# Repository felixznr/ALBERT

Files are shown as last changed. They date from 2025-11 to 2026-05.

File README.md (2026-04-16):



# ALBERT

Albert I was a rhesus macaque monkey and the first mammal launched on a rocket (V-2 Rocket "Blossom No. 3") on June 18, 1948. The launch was staged at Albert I, a nine-pound monkey, was anesthetized and placed inside the rocket's crew capsule in the nose of the V-2 rocket. The flight did not reach outer space. The last couple hours before his death, Albert was lit asf on morphine

---

## Project Overview

ALBERT is a self-regulating guided rocket project developed as a Maturaprojekt (Austrian graduation project). The goal is to build a fully functional, autonomous rocket system capable of correcting its own flight path and safely recovering via parachute deployment.

**Key Objectives:**
- Develop autonomous flight path correction through advanced control systems
- Implement fin-based steering for precise guidance
- Create a reliable parachute recovery system
- Design a concept of a custom solid fuel motor
- Integrate comprehensive telemetry and safety systems

## Team Structure

- **Timofey Luzin**: Recovery system, steering system, and structural components
- **Felix Zauner**: Flight computer development, control systems, simulation, and telemetry

## Repository Organization

```
├── 1_Documentation/        # Project documentation and requirements
├── 2_CAD_Structure/        # 3D models and structural designs  
├── 3_Flight_Computer/      # Flight computer hardware
├── 4_Simulation/           # Flight simulation and testing tools
└── 5_Codebase/             # Main source code and algorithms
```

For detailed technical specifications, see `1_Documentation/Diplomarbeit_ALBERT/chapter/main.pdf`.

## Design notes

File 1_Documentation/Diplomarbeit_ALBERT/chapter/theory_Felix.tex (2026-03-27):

\chapter{Platinendesign}
\label{ch:platinendesign}
\fancyfoot[C]{\large Felix Zauner}
\fancypagestyle{plain}{\fancyfoot[C]{\large Felix Zauner}}
Eine Platine ist eine gedruckte Schaltung (Printed Circuit Board, PCB in Englisch), die dazu dient, elektronische Bauteile miteinander zu verbinden. In diesem Kapitel werden die Grundlagen des Platinendesigns erörtert, einschließlich der Auswahl von Bauteilen, Layout-Strategien und Fertigungstechniken.
\\
Im Rahmen des Projektes wurde die Software KiCad eingesetzt, um den Schaltplan als auch das Layout der Platine zu erstellen. KiCad ist eine Open-Source-Software, die eine Vielzahl von Werkzeugen für das Design von Leiterplatten bereitstellt.
\\
Es ist von essentieller Bedeutung, sich vorab mit den Anforderungen an die Platine vertraut zu machen. Bei der Auswahl von Komponenten sind eine Vielzahl von Faktoren zu berücksichtigen. Dazu zählen elektrische Anforderungen, wie beispielsweise die Spannungs- und Stromstärken, mechanische Anforderungen, wie die Größe und Form der Platine, sowie Umweltanforderungen, wie die Betriebstemperatur, die Feuchtigkeitsbeständigkeit, aber auch Vibrationen und externe Störungen, Stichwort EMV, müssen, besonders bei der Bauteilauswahl, berücksichtigt werden.
\\
\\
Es ist in allen folgenden Punkten essentiell, sich zuvor mit den Produktionskapazitäten und -anforderungen des gewählten Platinenherstellers vertraut zu machen, um sicherzustellen, dass das Design den Fertigungsspezifikationen entspricht und somit eine reibungslose Produktion gewährleistet ist.
Darüber hinaus ist es ratsam, die Grenzen der Fertigungskapazitäten zu meiden, um Zusatzkosten zu vermeiden und potenzielle Fehlerquellen zu minimieren.

\section{Build-up \& Stack-up}
\label{sec:buildup_stackup}
\subsection{Build-up}
\label{subsec:buildup}

\begin{wrapfigure}{r}{0.5\textwidth}

    % {r} = rechtsbündig platzieren
    % Alternativen: {l} = links, {i} = innen (bei zweiseitigem Druck), {o} = außen
    % 0.4\textwidth = Gesamtbreite inkl. Abstand zum Text
    \centering
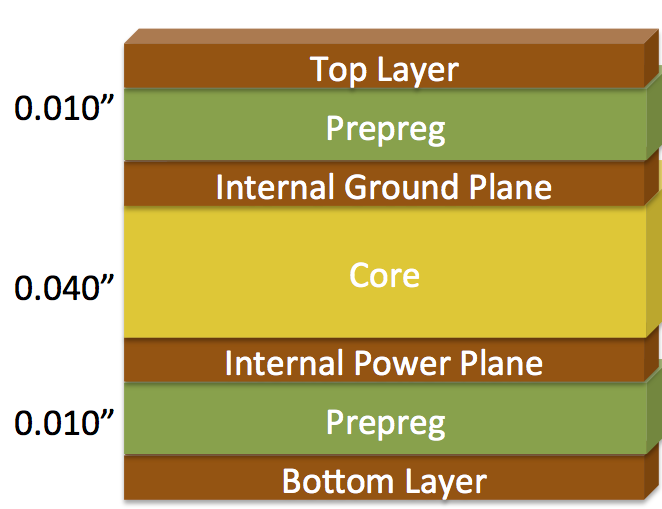
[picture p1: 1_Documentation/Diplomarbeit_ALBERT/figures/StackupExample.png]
    
        \caption{Beispielhafter Stackup einer vierlagigen Leiterplatte \parencite{bitweenie2013}}
        \label{fig:stackup_example}
    % Bildbreite etwas kleiner als wrapfigure-Breite (Abstand zum Text)

  % Abstand nach dem Bild reduzieren
\end{wrapfigure}
Der Leiterplattenaufbau (Build-up) einer Leiterplatte beschreibt den physikalischen Aufbau und die Anordnung der verschiedenen Schichten, aus denen die Platine besteht. Ein charakteristisches Build-up besteht aus einer Mehrzahl von Kupferschichten, die durch Isolationsmaterialien voneinander getrennt sind. Die Anzahl der Schichten sowie die Auswahl des dielektrischen Isolationsmaterials sind abhängig von der Komplexität der Schaltung und den Anforderungen an Signalqualität und Leistung. 
\\
In der Planungsphase sind primär die Anzahl der erforderlichen Lagen, die Auswahl der Isolationsmaterialien für den Kern sowie Prepreg und die Dicke der inneren und äußeren Kupferschichten festzulegen. \parencite{PhilsLab56}
\\
Die Abbildung \ref{fig:stackup_example} zeigt ein beispielhaftes Build-up und Stack-up einer vierlagigen Leiterplatte.
\\
\subsection{Stack-up}
\label{subsec:stackup}
Das Stack-up einer Leiterplatte beschreibt die Anordnung der verschiedenen Schichten in Bezug auf die elektrische Verwendung und Funktionalität. Das Stack-up umfasst die Definition von:
\begin{itemize}
        \item Ground-Layers $\rightarrow$ Referenzpotential für die Schaltung, Rückstrompfade
        \item Power-Layers  $\rightarrow$ Versorgungsspannungen für die Schaltung
        \item Signal-Layers $\rightarrow$ Leiterbahnen für die Signalübertragung
\end{itemize}
Des Weiteren besteht die Möglichkeit, Power- und Ground-Planes\footnote{Plane: Eine durchgehende Kupferfläche auf einer Leiterplattenlage, die als Referenzpotential oder Versorgungsspannung dient.} sowie Signal- und Ground-Planes auf einem Layer zu kombinieren. Auf diese Weise kann etwa auf zweilagigen Platinen Platz eingespart werden.
\\
Die Anordnung dieser Schichten im Stack-up ist entscheidend für gute EMV/EMI Eigenschaften, Signalintegrität und Leistungsverteilung. Ein gut durchdachtes Stack-up minimiert Störungen, verbessert die Signalqualität und gewährleistet eine zuverlässige Funktion der Schaltung.
\\\\
Die im folgenden Abschnitten beschriebenen Konzepte stellen die wichtigsten Prinzipien dar, die bei der Gestaltung eines effektiven Stack-ups zu berücksichtigen sind.
\subsubsection{Rückstrompfade}
\label{subsubsec:rueckstrompfade}
Ein kritischer Aspekt im Platinendesign ist die Gestaltung der Rückstrompfade für Signale. \\Rückstrompfade sind die Wege, die der Strom zurück zum Ursprungspunkt nimmt, nachdem er durch die Schaltung geflossen ist. 
\\
Für Gleichspannung nimmt der Rückstrom den Weg des geringsten ohmschen Widerstands über die nächste Massefläche. Bei Wechselspannung ($>kHz$) hingegen folgt der Rückstrompfad dem Signalpfad, da die kapazitive und induktive Kopplung zwischen den Leitungen dominant wird. \parencite{ZachariahPeterson_Rückstromführung}

\begin{figure}[H]
  \centering
  % Erste Unterabbildung (Subfigure)
  \begin{subfigure}[b]{0.49\textwidth}
    % [b] = bottom-aligned (unten ausgerichtet)
    % Alternativen: [t] = top, [c] = center
    % 0.45\textwidth = 45% der Textbreite
    \centering
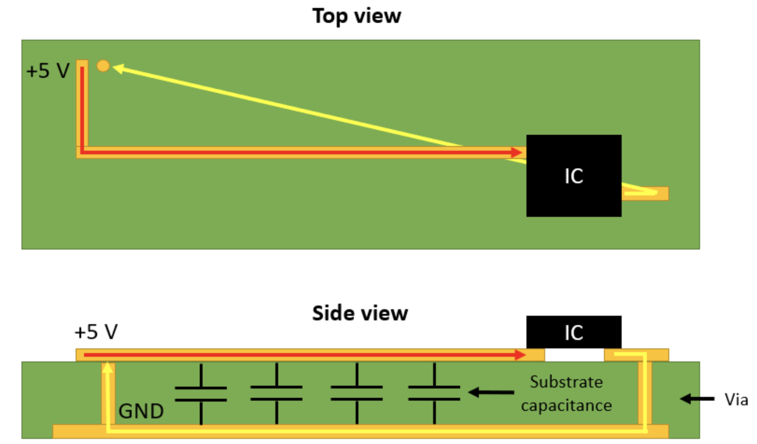
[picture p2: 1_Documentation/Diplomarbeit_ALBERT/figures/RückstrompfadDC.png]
    
    % \textwidth bezieht sich hier auf die Subfigure-Breite (45%)
    \caption{Rückstrompfad für Gleichstrom}
    % Separate Bildunterschrift für diese Subfigure
    \label{fig:sub-mercedes}
    % Eigenes Label für Referenzierung
  \end{subfigure}
  \hfill
  % \hfill = maximaler horizontaler Abstand (verteilt Bilder gleichmäßig)
  % Alternative: \hspace{1cm} für festen Abstand
  \begin{subfigure}[b]{0.49\textwidth}
    \centering
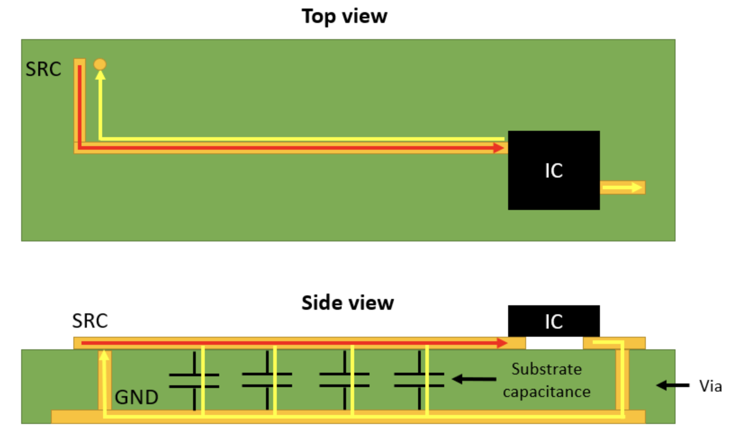
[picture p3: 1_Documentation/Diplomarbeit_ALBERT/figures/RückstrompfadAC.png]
    
    \caption{Rückstrompfad für Wechselstrom}
    \label{fig:sub-porsche}
  \end{subfigure}
  \caption{Rückstrompfade im Vergleich \parencite{ZachariahPeterson_Rückstromführung}}
  % Gemeinsame Hauptbildunterschrift für beide Subfigures
  \label{fig:zwei-neben}
  % Hauptlabel für die gesamte Figure
\end{figure}
\newpage
\subsubsection{Energiefluss}
\label{subsubsec:energiefluss}
Für eine optimale Signalübertragung und minimale Störungen ist es entscheidend, den Energiefluss zwischen den Leiterbahnen und den zugehörigen Ground- und Power-Planes zu verstehen. 
\begin{wrapfigure}{r}{0.5\textwidth}

  % {r} = rechtsbündig platzieren
  % Alternativen: {l} = links, {i} = innen (bei zweiseitigem Druck), {o} = außen
  % 0.4\textwidth = Gesamtbreite inkl. Abstand zum Text
  \centering
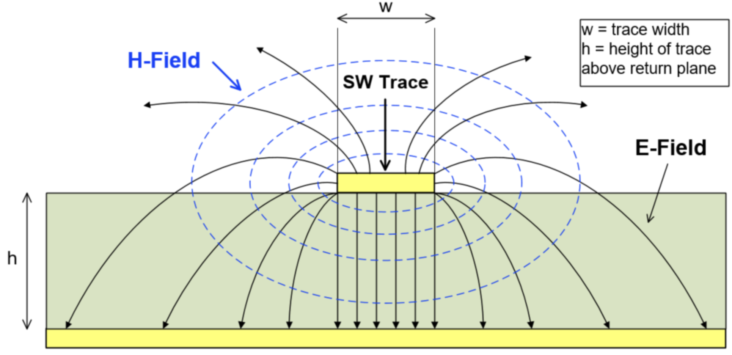
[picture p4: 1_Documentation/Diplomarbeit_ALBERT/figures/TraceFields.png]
  
    \caption{Elektrisches und magnetisches Feld eines Leiterbahnschnitts \parencite{ToddToporski_EMC}}
    \label{fig:trace_fields}
  % Bildbreite etwas kleiner als wrapfigure-Breite (Abstand zum Text)

    % Abstand nach dem Bild reduzieren
\end{wrapfigure}
Jede Leiterbahn erzeugt ein elektrisches Feld (E-Feld) und ein magnetisches Feld (H-Feld) um sich herum, wenn Strom durch sie fließt. Die Energieübertragung erfolgt durch diese Felder. Das elektrische Feld ist zwischen der Leiterbahn und dem nächstgelegenen Ground-Plane konzentriert, während das magnetische Feld konzentrisch um die Leiterbahn verläuft.
Dabei stellen die Kupferbahnen den Waveguide für die Felder dar. 
\\
Die Abbildung \ref{fig:trace_fields} veranschaulicht die Verteilung der elektrischen und magnetischen Felder um eine Leiterbahn.
\\\\
Um nun die Signalintegrität zu gewährleisten und Crosstalk \footnote{Crosstalk bezeichnet bei Leiterplatten das unerwünschte Übersprechen von Signalen zwischen benachbarten Leiterbahnen, verursacht durch kapazitive und induktive Kopplung} sowie EMI zu minimieren, ist es wichtig, dass sich die Felder der Leiterbahnen nicht ausbreiten und mit deren von benachbarten Leiterbahnen verursachten Feldern koppeln. 
\\
Dies kann durch zwei wesentliche Maßnahmen erreicht werden:
\begin{itemize}
    \item Minimierung des Abstands $h$ zwischen der Leiterbahn und dem zugehörigen Ground-Plane
    \item Maximierung des Abstands zu benachbarten Leiterbahnen
\end{itemize}
\vspace{0.5cm}
Aus diesen beiden Punkten können folgende Designregeln für das Layout der Leiterplatte abgeleitet werden:
\begin{itemize}
    \item Der Abstand $h$ zwischen der Leiterbahn und der zugehörigen Ground-Plane sollte so klein wie möglich gehalten werden, daher wäre es ideal, wenn jede Signal-Leiterbahn direkt über einer Ground-Plane verlaufen würde.
    \item Jede Signal-Leiterbahn sollte einen ununterbrochenen Rückstrompfad haben.
\end{itemize}
\parencite{PhilsLab56}
\newpage

\section{Bypass- \& Decoupling-Kondensatoren}
\label{sec:bypass_decoupling}
Bypass- und Decoupling-Kondensatoren sind wesentliche Komponenten in der Entwicklung von Leiterplatten, die dazu dienen, Störungen zu minimieren und eine stabile Versorgungsspannung für ICs bereitzustellen. Oft werden die Begriffe Bypass- und Decoupling-Kondensatoren synonym verwendet, obwohl sie strenggenommen unterschiedliche Funktionen erfüllen.
\\\\
\textbf{Bypass-Kondensatoren} werden verwendet, da Kondensatoren bei hohen Frequenzen einen niedrigen Impedanzwert aufweisen. Sie leiten hochfrequente Störsignale von der Versorgungsspannung gegen Masse ab und dienen als Filter, um zu verhindern, dass Störungen in die Schaltung eindringen und die Funktion der Bauteile beeinträchtigen.
\\\\
\textbf{Decoupling-Kondensatoren} hingegen werden direkt an den Versorgungspins von ICs platziert, um schnelle Stromänderungen lokal auszugleichen, die durch das Schalten der internen Transistoren verursacht werden. Sie stellen sicher, dass die Versorgungsspannung stabil bleibt und verhindert Spannungsschwankungen.
\parencite{JLCDecouplingBypass}
\\\\
Bei der Platzierung von Bypass- und Decoupling-Kondensatoren auf der Leiterplatte sind folgende Richtlinien zu beachten:
\begin{itemize}
    \item \textbf{Nähe zum IC}: Decoupling-Kondensatoren sollten so nah wie möglich an den Versorgungspins des ICs platziert werden und mit möglichst breiten Leiterbahnen verbunden werden, um die Induktivität der Leiterbahnen zu minimieren. Die Vias zu Masse und Power sollten ebenfalls so nah wie möglich am Kondensator platziert werden.
    \item \textbf{Verschiedene Werte}: In vielen Fällen erweist es sich als sinnvoll, mehrere \\Decoupling-Kondensatoren mit unterschiedlichen Kapazitätswerten (typischerweise $100nF$ und $10 \mu F$, Keramik) zu verwenden. Aufgrund der Tatsache, dass kleinere Kondensatoren dazu in der Lage sind, Energie schneller bereitzustellen, empfiehlt es sich, diese näher am IC zu platzieren. 
    \item \textbf{Bypass-Kondensatoren}: Diese sollten strategisch in der Nähe von kritischen Versorgungspunkten auf der Platine platziert werden, um Störungen effektiv abzuleiten. So etwa an der Analogversorgung von Mikrocontrollern.
\end{itemize}
Auch hier gilt wieder, die Empfehlungen des Herstellers der jeweiligen Bauteile zu beachten um eine optimale Funktion zu gewährleisten.
\begin{figure}[H]
\centering
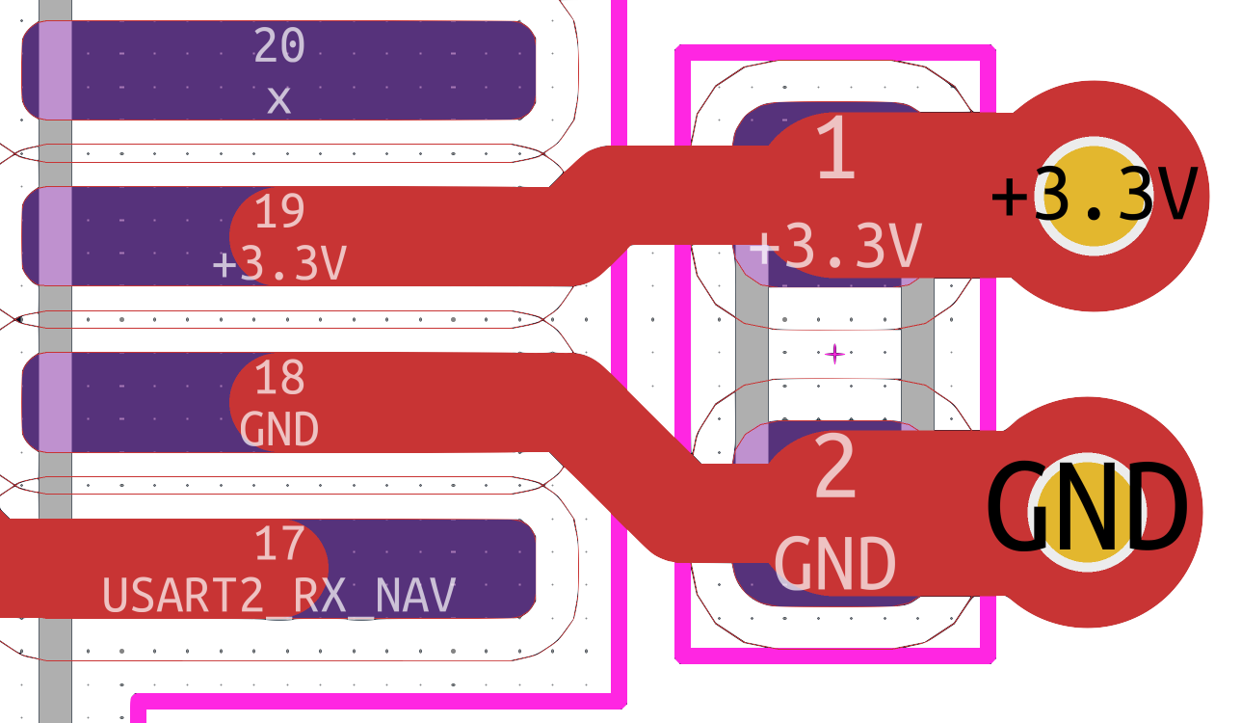
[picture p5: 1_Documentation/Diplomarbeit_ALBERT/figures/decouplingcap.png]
    
    \caption{Platzierung von Decoupling-Kondensatoren}
    \label{fig:decoupling_cap}
\end{figure}
\newpage
\section{Abwärtswandler}
\label{sec:abwaertswandler}
Der Abwärtswandler (Buck Converter) ist ein DC-DC-Wandler, der eine höhere Eingangsspannung in eine niedrigere Ausgangsspannung umwandelt. Durch einen getakteten Schaltvorgang wird die Energieübertragung gesteuert, was zu einer verbesserten Effizienz im Vergleich zu linearen Spannungsreglern führt.
\\
Für den kontinuierlichen Betrieb\footnote{kontinuierlicher Betrieb - der Strom $I_L$ wird während des gesamten Zykluses nie 0} gilt folgender Zusammenhang zwischen Ein- und Ausgangsspannung:
\begin{equation}
    U_{A} = U_{E} \cdot \frac{t_{1}}{T}
\end{equation}
\begin{figure}[H]
    \centering
    \begin{tikzpicture}
	% Paths, nodes and wires:
	\draw (4.875, 2) to[empty diode, l={$D$}] (4.875, 5);
	\draw (4.375, 5) to[european inductor, l={$L$}] (7.375, 5);
	\draw (6.875, 5) to[capacitor, l={$C_{A}$}] (6.875, 2);
	\draw (7.875, 5) -- (9.875, 5);
	\node[circ] at (0.335, 5){};
	\node[circ] at (0.335, 2){};
	\node[circ] at (9.875, 5){};
	\node[circ] at (9.875, 2){};
	\node[ground] at (4.875, 2){};
	\draw (7.875, 2) -- (9.875, 2);
	\draw[-stealth] (0.335, 4.75) -- (0.335, 2.25);
	\draw[line width=0.9pt, -stealth] (9.875, 4.75) -- (9.875, 2.25);
	\node[shape=rectangle, minimum width=0.965cm, minimum height=0.715cm](N1) at (-0.125, 3.625){} node[anchor=center] at (N1.text){$U_{E}$};
	\node[shape=rectangle, minimum width=0.965cm, minimum height=0.715cm](N2) at (10.375, 3.375){} node[anchor=center] at (N2.text){$U_{A}$};
	\draw[-stealth] (4.5, 5) -- (5.2, 5);
	\node[shape=rectangle, minimum width=0.965cm, minimum height=0.715cm](N3) at (4.9, 5.375){} node[anchor=center] at (N3.text){$I_{L}$};
	\draw[-stealth] (4.875, 4.25) -- (4.875, 4.5);
	\node[shape=rectangle, rotate=90, minimum width=0.965cm, minimum height=0.715cm](N4) at (4.625, 4.25){} node[anchor=center] at (N4.text){$I_{D}$};
	\draw[-stealth] (1.375, 5) -- (1.625, 5);
	\node[shape=rectangle, minimum width=0.965cm, minimum height=0.715cm](N5) at (1.335, 5.375){} node[anchor=center] at (N5.text){$I_{E}$};
	\draw[-stealth] (9.375, 5) -- (9.625, 5);
	\node[shape=rectangle, minimum width=0.965cm, minimum height=0.715cm](N6) at (9.375, 5.375){} node[anchor=center] at (N6.text){$I_{A}$};
	\node[nigfete, rotate=90](N7) at (2.605, 5){} node[anchor=south] at (N7.text){$Q$};
	\draw (3.375, 5) -- (4.375, 5);
	\draw (0.335, 5) -- (1.835, 5);
	\node[shape=rectangle, draw, line width=1pt, minimum width=1.715cm, minimum height=0.715cm] at (3.125, 3.375){};
	\node[shape=rectangle, minimum width=1.465cm, minimum height=0.715cm] at (3.125, 3.375){} node[anchor=north, align=center, text width=1.077cm, inner sep=6pt] at (2.83, 3.75){Controller};
	\draw (2.874, 4.02) -| (2.875, 3.75);
	\draw (8.375, 5) to[european resistor, l={$R_{FB1}$}] (8.375, 3.5);
	\draw (8.375, 3.5) to[european resistor, l={$R_{FB2}$}] (8.375, 2);
	\draw (6.875, 5) -- (7.875, 5);
	\draw (7.875, 2) -- (6.875, 2);
	\draw (6.835, 2) |- (4.335, 2) -- (0.335, 2);
	\draw[dash pattern={on 1.6pt off 1.6pt}] (2.875, 3) |- (3, 1) -| (9.625, 3.5) -- (8.375, 3.5);
	\draw (1.125, 5) to[capacitor, l={$C_{E}$}] (1.125, 2);
\end{tikzpicture}
    \caption{Vereinfachter Schaltplan eines Abwärtswandlers}
    \label{fig:buck_converter}
\end{figure}
\vspace{-2.5cm}
\subsection{Funktionsweise}
\label{subsec:buck_funktionsweise}
Der MOSFET $Q$ wird periodisch durch einen Regler (Controller) ein- und ausgeschaltet, wodurch während der Einschaltphase $t_{1}$ der Ausgangsstrom $I_{A}$ durch die Induktivität $L$ und die angeschlossene, aber hier nicht eingezeichnete Last fließt. Die Diode $D$ ist in dieser Phase gesperrt. Während der Ausschaltphase  hingegen sperrt der MOSFET $Q$ und die Induktivität $L$ entlädt sich über die Diode $D$ und die Last um den Stromfluss aufrechtzuerhalten. 
\\
Der Kondensator $C_A$ lädt sich in dieser Phase so lang auf bis beide das gleiche Potenzial erreicht haben, danach stützt er die Ausgangsspannung $U_{A}$. Der Eingangskondensator $C_E$ stellt die hochfrequenten, gepulsten Eingangsstromanteile bereit und wirkt dabei als lokaler Energiespeicher, wodurch Eingangsspannungsripple, Spannungsspitzen und EMV-Störungen reduziert und die Spannungsquelle entlastet werden. 
\\
Durch die kontinuierliche Ein- und Ausschaltphase wird eine mittlere Ausgangsspannung $\bar{U}_{A}$ erzeugt, die niedriger ist als die Eingangsspannung $U_{E}$ und über die Schaltfrequenz gesteuert werden kann.
\\
Über den Feedback-Widerstandsteiler $R_{FB1}$ und $R_{FB2}$ wird die Ausgangsspannung $U_{A}$ dem Controller zurückgeführt, der das Tastverhältnis $\frac{t_1}{T}$ (duty cycle) des MOSFETs $Q$ anpasst, um die gewünschte Ausgangsspannung zu halten.
\parencite{schmidt-walter_Abwärtswandler}\parencite{PhilsLab60}

\begin{figure}[H]
  \centering
  \begin{tikzpicture}[scale=1]

    % Gitternetz
      \draw[gray!20] (0,0) grid (9,5);
      \draw[gray!40] (0,0) grid[step=2] (9,5);

      % Bereich 1: MOSFET AN (0 bis t1)
      \draw[gray!20, fill=green!10] (0,0) -- (3,0) -- (3,5) -- (0,5) -- cycle;
      \node[green, anchor=south] at (1.5, 5) { Q AN};
      
      % Bereich 2: MOSFET AUS (t1 bis T)
      \draw[gray!20, fill=red!10] (3,0) -- (6,0) -- (6,5) -- (3,5) -- cycle;
      \node[red, anchor=south] at (4.5, 5) { Q AUS};

      % Bereich 1: MOSFET AN (0 bis t1)
      \draw[gray!20, fill=green!10] (6,0) -- (9,0) -- (9,5) -- (6,5) -- cycle;
      \node[green, anchor=south] at (7.5, 5) { Q AN};
      
      % --- U_Q (Schaltspannung) ---
      \draw[line width=1pt, blue!50] (0,5) -- (3,5) -- (3,0) -- (6,0) -- (6,5) -- (9,5);
      \node[blue!50, left] at (0,4.5) {$U_Q$};
      
      % --- U_A (Ausgangsspannung) ---

      \draw[line width=1.5pt, orange] (0,2.5) -- (1.5,2);

      \draw[line width=1.5pt, orange] (1.5,2) -- (4.5,3);
      \draw[line width=1.5pt, orange] (4.5,3) -- (6,2.5);
      \draw[line width=1.5pt, orange] (6,2.5) -- (7.5,2);
      \draw[line width=1.5pt, orange] (7.5,2) -- (9,2.5);
       
      \node[orange, left] at (0,2.8) {$U_A$};
      
      % --- I_L (Induktivitätsstrom) ---
      % Phase 1: Strom steigt linear
      \draw[line width=1.5pt, purple] (0,1.5) -- (3,3.5);
      % Phase 2: Strom fällt linear
      \draw[line width=1.5pt, purple] (3,3.5) -- (6,1.5);
      % Periodische Wiederholung
      \draw[line width=1.5pt, purple] (6,1.5) -- (9,3.5);
      
      % Strommittelwert
      \draw[dashed, orange] (0,2.5) -- (9,2.5) node[right] {$\bar{U}_A$};
      \node[purple, left] at (0,1.2) {$I_L$};
      
      % Achsen
      \draw[->] (0,0) -- (9.25,0) node[right] {$t$};
      \draw[->] (0,0) -- (0,5.25) node[above] {I / U};
      
      % Messpfeile
      \draw[<->] (0,-0.2) -- (3,-0.2) node[midway, below] {$t_1$};
      \draw[<->] (0,-0.7) -- (6,-0.7) node[midway, below] {$T$};
    
  \end{tikzpicture}
  \caption{Zeitliche Verläufe von Schaltspannung $U_Q$, Ausgangsspannung $U_A$ und Induktivitätsstrom $I_L$ eines Buck Converters im kontinuierlichen Betrieb}
  \label{fig:buck_waveforms}
\end{figure}

\subsection{Layoutrichtlinien}
\label{subsec:buck_layoutrichtlinien}
Beim Layout eines Abwärtswandlers gilt es mehrere kritische Aspekte zu berücksichtigen, um eine stabile und saubere Spannungsversorgung zu gewährleisten, hierzu ist es sinnvoll, sich an Referenzdesigns sowie Bauteilempfehlungen der Hersteller zu orientieren.
\begin{wrapfigure}{r}{0.5\textwidth}
\vspace{10pt}
  % {r} = rechtsbündig platzieren
  % Alternativen: {l} = links, {i} = innen (bei zweiseitigem Druck), {o} = außen
  % 0.4\textwidth = Gesamtbreite inkl. Abstand zum Text
  \centering
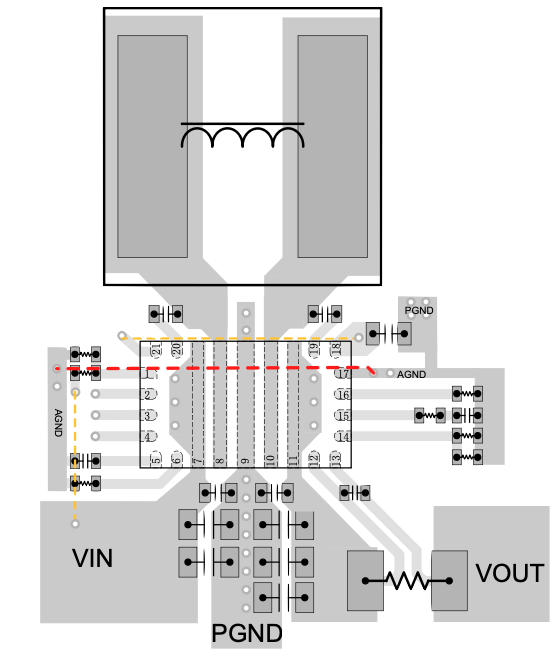
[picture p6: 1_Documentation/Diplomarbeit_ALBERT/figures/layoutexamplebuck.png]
    
    \caption{Beispielhaftes Layout eines Abwärtswandlers \parencite{TPS55289}}
    \label{fig:buck_layout_example}
  % Bildbreite etwas kleiner als wrapfigure-Breite (Abstand zum Text)
    \vspace{-1cm}
  % Abstand nach dem Bild reduzieren
\end{wrapfigure}

\begin{itemize}
   \item \textbf{Schleifen kurz halten}: Die Stromschleifen, insbesondere die Schleife, die durch den MOSFET $Q$, die Diode $D$, die Induktivität $L$ und den Eingangskondensator $C_E$ gebildet wird, sollten so kurz wie möglich gehalten werden, um parasitäre Induktivitäten und elektromagnetische Störungen zu minimieren.
   \item \textbf{Kritische Pfade zuerst routen}: Hochfrequente sowie stromtragende Leiterbahnen, wie die Verbindungen zwischen $Q$, $D$, $L$ und $C_A$, sollten zuerst geroutet werden, um deren optimale Platzierung und minimale Länge sicherzustellen. Feedback Leitungen können später und weit weg von Störquellen geroutet werden.
   \item \textbf{Power und Ground Puddles nutzen}: Verwendung von durchgehenden Power- und Ground-Planes, mit sauberer Trennung der Signale zur Minimierung von Störungen. 
\end{itemize}
\parencite{PhilsLab60}

\newpage
\section{Sensorik}
\label{sec:sensorik}
Zur Erfassung der benötigten Messgrößen für das Regelungssystem werden verschiedene Sensoren eingesetzt. Diese Sensoren wandeln physikalische Größen in elektrische Signale um, die von der Steuerungseinheit verarbeitet werden können.
\subsection{Inertial Measurement Unit}
\label{subsec:imu}
\begin{wrapfigure}{r}{0.35\textwidth}
\vspace{-20pt}
  % {r} = rechtsbündig platzieren
  % Alternativen: {l} = links, {i} = innen (bei zweiseitigem Druck), {o} = außen
  % 0.4\textwidth = Gesamtbreite inkl. Abstand zum Text
  \centering
   
% Kameraperspektive
\tdplotsetmaincoords{65}{115}

\begin{tikzpicture}[tdplot_main_coords, scale=3]

% Ursprung
\coordinate (O) at (0,0,0);

% Achsen
\draw[->, thick] (O) -- (1,0,0) node[anchor=north] {$x$};
\draw[->, thick] (O) -- (0,0.8,0) node[anchor=west] {$y$};
\draw[->, thick] (O) -- (0,0,0.8) node[anchor=south east] {$z$};

% Flache IMU-Platine
\draw[fill=gray!25] (-0.25,-0.18,-0.03) -- (0.25,-0.18,-0.03) --
                    (0.25,0.18,-0.03) -- (-0.25,0.18,-0.03) -- cycle;
\draw[fill=gray!35] (-0.25,-0.18,0.03) -- (0.25,-0.18,0.03) --
                    (0.25,0.18,0.03) -- (-0.25,0.18,0.03) -- cycle;

\foreach \x/\y in { 0.25/-0.18, 0.25/0.18, -0.25/0.18}
  \draw (\x,\y,-0.03) -- (\x,\y,0.03);

\node at (0,0,0.05) {\scriptsize IMU};

% Accelerometer
\node[blue] at (0.9,-0.15,0) {$a_x$};
\node[blue] at (0.2,0.9,0) {$a_y$};
\node[blue] at (0,0.05,0.9) {$a_z$};

% Gyroskop
% ω_x : Rotation um x-Achse (in y–z-Ebene)
\tdplotsetrotatedcoords{0}{0}{180}
\tdplotdrawarc[
  tdplot_rotated_coords,
  red, thick, ->]
  {(0,0,0.5)}{0.2}{0}{270}
  {anchor=north}{$\omega_z$}

% ω_y : Rotation um y-Achse (in x–z-Ebene)
\tdplotsetrotatedcoords{90}{90}{0}
\tdplotdrawarc[
  tdplot_rotated_coords,
  red, thick, ->]
  {(0,0,0.5)}{0.2}{0}{270}
  {anchor=west}{$\omega_y$}

% ω_z : Rotation um z-Achse (in x–y-Ebene)
\tdplotsetrotatedcoords{0}{90}{90}
\tdplotdrawarc[
  tdplot_rotated_coords,
  red, thick, ->]
  {(0,0,0.5)}{0.2}{0}{270}
  {anchor=east}{$\omega_x$}

% Legende
\node[blue] at (0,0.8,0.8) {Beschleunigungssensor};
\node[red]  at (0,0.8,0.6) {Gyroskop};

\end{tikzpicture}
    \caption{Messgrößen einer 6-DOF IMU}
    \label{fig:imu_example}
  % Bildbreite etwas kleiner als wrapfigure-Breite (Abstand zum Text)

  % Abstand nach dem Bild reduzieren
\vspace{0.5cm}
\end{wrapfigure}
Eine Inertial Measurement Unit (IMU) ist ein Bauteil, das mehrere Inertialsensoren kombiniert, um die Bewegungs- und Lageänderungen eines Objekts zu messen. 
 Beschleunigungssensoren messen die lineare Beschleunigung $a$ in verschiedenen Achsen, während Gyroskope die Winkelgeschwindigkeit $\omega$ um diese Achsen erfassen. Durch Integration dieser Messwerte können Position, Geschwindigkeit und Orientierung des Systems bestimmt werden.
\\
In vorliegendem Projekt finden moderne IMUs Anwendung, die MEMS-Technologie nutzen, um kompakte und energieeffiziente Sensoren bereitzustellen, welche auf der Platine integriert werden können.
\parencite{AdvancedNavigation_IMU}

\subsubsection{Funktionsweise von MEMS Beschleunigungssensoren}
\label{subsubsec:mems_accelerometer}
Die Messung der Beschleunigung in MEMS-Beschleunigungssensoren basiert auf der Erfassung der Trägheitskräfte, die auf eine kleine Masse (Proof Mass) wirken, wenn das Gerät beschleunigt wird. Diese Masse ist über mikroskopisch kleine Federstrukturen mit einem internen Rahmen verbunden. 
\\
Die Messung der Lageverschiebung der Proof Mass erfolgt durch kapazitive Messung. Dabei bilden die bewegliche Masse und feste Elektroden Kondensatoren, deren Kapazität sich ändert, wenn die Masse aufgrund der Beschleunigung ihre Position verändert. Dabei werden mehrere dieser Strukturen in verschiedenen Achsen angeordnet, um die dreidimensionale Beschleunigung zu erfassen. \parencite{AdvancedNavigation_IMU}
\begin{wrapfigure}{l}{0.4\textwidth}

  % {r} = rechtsbündig platzieren
  % Alternativen: {l} = links, {i} = innen (bei zweiseitigem Druck), {o} = außen
  % 0.4\textwidth = Gesamtbreite inkl. Abstand zum Text
  \centering
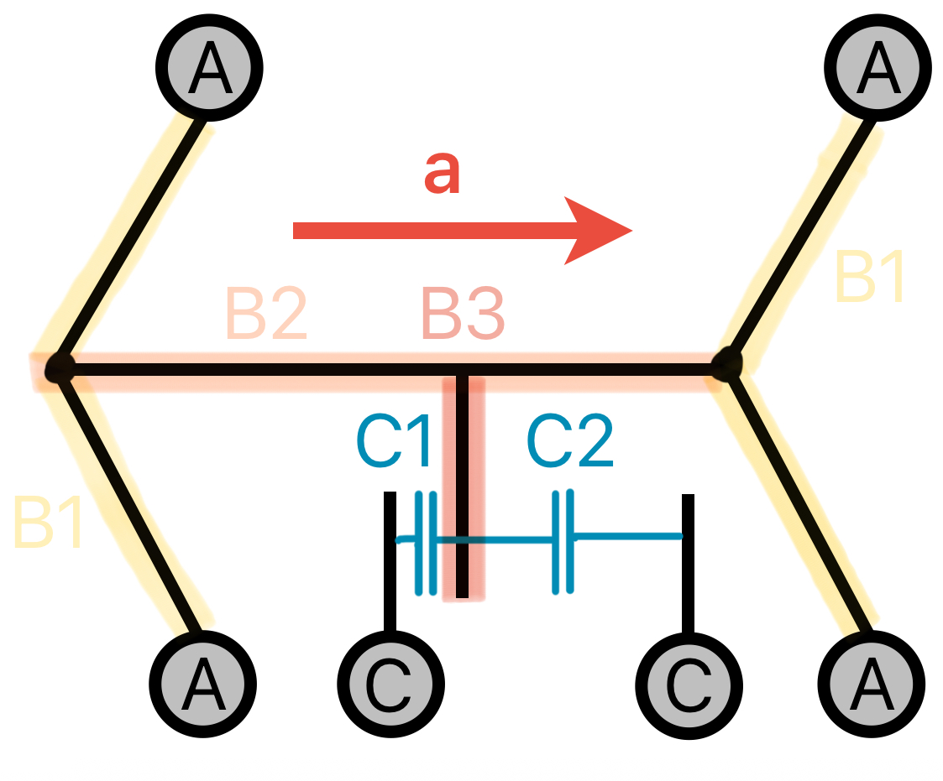
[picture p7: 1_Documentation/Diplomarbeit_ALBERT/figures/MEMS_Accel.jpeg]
    
    \caption{Schematische Darstellung eines MEMS-Beschleunigungssensors }
    \label{fig:mems_accel}
  % Bildbreite etwas kleiner als wrapfigure-Breite (Abstand zum Text)

  % Abstand nach dem Bild reduzieren
    \vspace{-3cm}
\end{wrapfigure}
\\
In der Abbildung \ref{fig:mems_accel} ist eine schematische Darstellung eines Segments eines MEMS-Beschleunigungssensors zu sehen. Die Proof Mass $B$ ist in der Mitte angeordnet und durch Federstrukturen $B1$ mit dem Rahmen $A$ verbunden. $B2$ bildet den zentralen Teil der Proof Mass auf welcher mehrere vorstehende Finger $B3$ sitzen. Elektroden $C$ auf beiden Seiten der Masse bilden die Kondensatoren $C1$ \& $C2$, deren Kapazitätsänderung gemessen wird, um die Beschleunigung zu bestimmen.
\\
\vspace{2cm}
\subsubsection{Funktionsweise von MEMS Gyroskop}
\label{subsubsec:mems_gyroscope}
Um die Winkelgeschwindigkeit zu messen, nutzen MEMS-Gyroskope das Coriolis-Prinzip. Hierzu wird eine über Federn $A$ mit dem inneren Rahmen $C$ verbundene kleine Masse (Proof Mass) $B$ in Schwingung versetzt. Dieser Referenzrahmen ist wiederum über Federn $E$ mit dem äußeren Rahmen $D$ verbunden.
\\
Wenn das Gyroskop rotiert, wirkt auf die schwingende Masse eine Coriolis-Kraft, die eine sekundäre Schwingung der Masse verursacht. Diese Verschiebung wird ebenfalls kapazitiv über die Verschiebung der Rahmen gemessen, ähnlich wie bei den Beschleunigungssensoren. Die Größe der Verschiebung ist proportional zur Winkelgeschwindigkeit des Gyroskops. \parencite{AdvancedNavigation_IMU}
\vspace{-0.5cm}
\begin{figure}[H]
    \centering
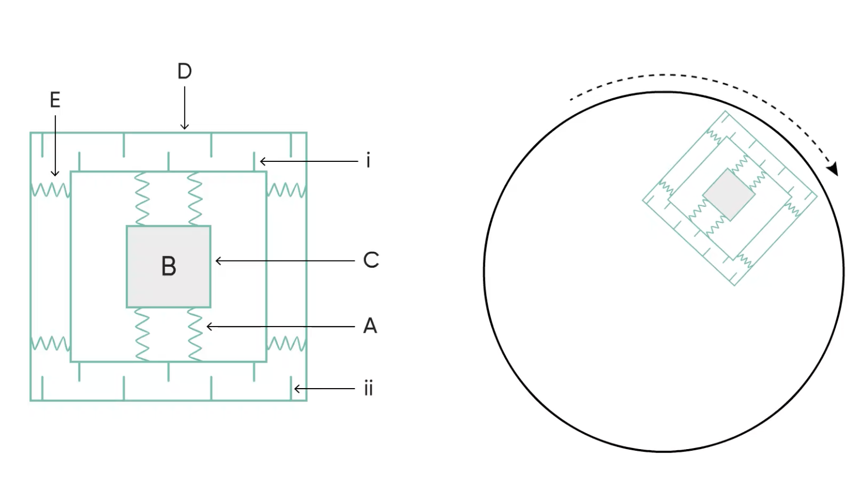
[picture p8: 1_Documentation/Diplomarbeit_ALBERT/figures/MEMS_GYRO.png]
        
        \caption{Schematische Darstellung eines MEMS-Gyroskops \parencite{AdvancedNavigation_IMU}}
        \label{fig:mems_gyro}
\end{figure}

\subsection{Magnetometer}
\label{subsec:magnetometer}
Magnetometer messen das Magnetfeld der Erde und liefern Informationen zur Orientierung des Systems relativ zum Erdmagnetfeld. Diese Daten können verwendet werden, um die Ausrichtung des Systems zu bestimmen und Korrektionen in der Regelung vorzunehmen.
\\
Es gibt verschiedene Technologien zur Messung von Magnetfeldern, darunter Hall-Effekt-Sensoren, Fluxgate-Magnetometer und magnetoresistive Sensoren.
\\
\begin{wrapfigure}
{r}{0.45\textwidth}
\vspace{-10pt}
  % {r} = rechtsbündig platzieren
  % Alternativen: {l} = links, {i} = innen (bei zweiseitigem Druck), {o} = außen
  % 0.4\textwidth = Gesamtbreite inkl. Abstand zum Text
  \centering
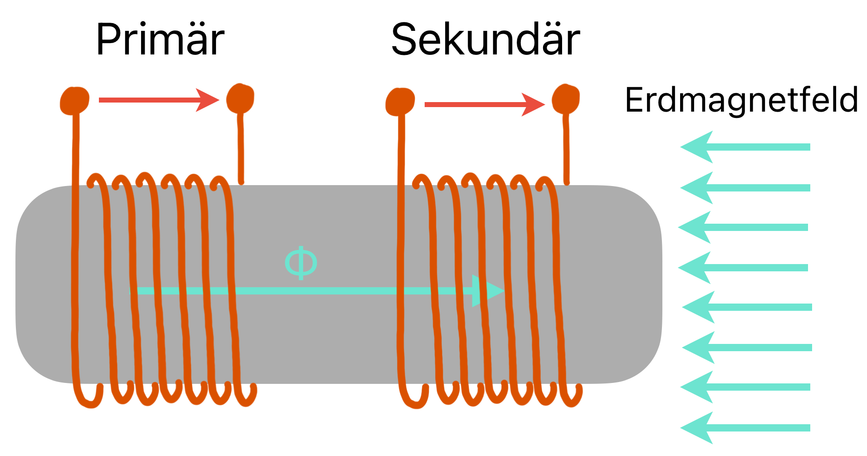
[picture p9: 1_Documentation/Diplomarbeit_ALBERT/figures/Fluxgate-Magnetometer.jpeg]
    
    \caption{Funktionsprinzip eines Fluxgate-Magnetometers }
    \label{fig:fluxgate_principle}
  % Bildbreite etwas kleiner als wrapfigure-Breite (Abstand zum Text)   
  \vspace{10pt}
\end{wrapfigure}
Hier soll nun die für dieses Projekt relevante Funktionsprinzip eines Fluxgate-Magnetometers in seiner einfachsten Form erläutert werden: Die Messung basiert auf einem ferromagnetischen Kern, der von einer Primärspule umgeben ist, durch die ein Wechselstrom fließt. Dieser Strom erzeugt ein magnetisches Wechselfeld im Kern, das diesen periodisch in Sättigung bringt. Eine Sekundärspule, die ebenfalls den Kern umgibt, detektiert die Änderung des magnetischen Flusses im Kern, die durch das externe waagrechte Magnetfeld beeinflusst wird. Wenn ein externes Magnetfeld vorhanden ist, ändert sich die Zeit, die der Kern benötigt, um in die Sättigung zu gelangen, was zu einer Änderung der induzierten Spannung in der Sekundärspule führt. Diese Spannung kann gemessen und zur Bestimmung der Stärke und Richtung des externen Magnetfelds verwendet werden.
\\
Das in diesem Projekt eingesetzte Magnetometer verwendet eine von Bosch Sensortec patentierte Technologie namens FlipCore, welche auf dem Fluxgate-Prinzip basiert, sich jedoch in einem wichtigen Punkt von dieser unterscheidet: Sie kann viel kompakter gebaut werden. Die Unterschiede in der Funktionsweise gestalten sich wie folgt: Eine Ummagnetisierung des Kernmaterials erfolgt durch Verschiebung mindestens einer Bloch-Wand\footnote{Bloch-Wand - Verdrehter Übergangsbereich zwischen zwei gegensätzlich gepolten Weißschen Bezirke}, anstatt wie bei dem Fluxgate-Prinzip durch eine gesamtheitliche Umpolung der Weißschen Bezirke\footnote{Weißsche Bezirke - Bereiche innerhalb eines ferromagnetischen Materials, in denen die magnetischen Momente der Atome parallel ausgerichtet sind}. Dies führt zu einer steileren Hysteresekurve und somit zu einer höheren Empfindlichkeit bei der Messung von Magnetfeldern, was es wiederum erlaubt kleiner zu bauen (MEMS). \parencite{BoschFlipCore}
\subsection{Barometer}
\label{subsec:barometer}

\begin{wrapfigure}
{r}{0.3\textwidth}
\vspace{-10pt}
  % {r} = rechtsbündig platzieren
  % Alternativen: {l} = links, {i} = innen (bei zweiseitigem Druck), {o} = außen
  % 0.4\textwidth = Gesamtbreite inkl. Abstand zum Text
  \centering
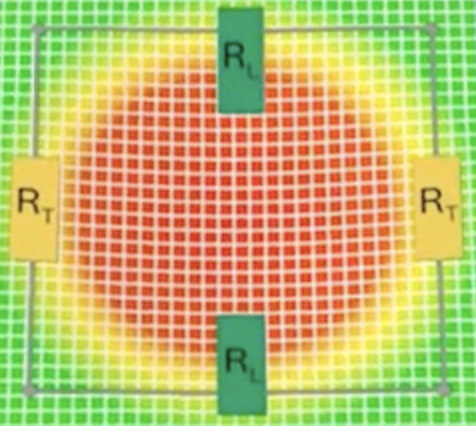
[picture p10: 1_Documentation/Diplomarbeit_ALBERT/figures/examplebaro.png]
    
    \caption{Beispielhafter Aufbau eines piezoresistiven Barometers \parencite{barometerWorkingPrinciple}}
    \label{fig:barometer_principle}
  % Bildbreite etwas kleiner als wrapfigure-Breite (Abstand zum Text)   
  \vspace{10pt}
\end{wrapfigure}
Barometer messen den Luftdruck und können zur Höhenbestimmung des Systems verwendet werden. Veränderungen im Luftdruck korrelieren mit Änderungen in der Höhe, was für die Regelung der vertikalen Position des Systems von Bedeutung ist.\\
Der in diesem Projekt eingesetzte Barometer-Sensor basiert auf einem piezoresistiven Prinzip, bei dem der Luftdruck eine Verformung einer dünnen Membran verursacht.  Diese in Abbildung \ref{fig:barometer_principle} rot dargestellte Verformung hat eine Veränderung des Widerstands der integrierten piezoresistiven Elementen zur Folge. Die resultierende Spannungsänderung wird gemessen und über das digitale Interface des Sensors ausgegeben. Es handelt sich wieder um MEMS-Technologie.

\newpage

\section{Global Navigation Satellite System (GNSS)}
\label{sec:gnss}

Global Navigation Satellite System (GNSS) ist ein Sammelbegriff für Satellitennavigationssysteme, die es ermöglichen, die Position eines Empfängers auf der Erde mit hoher Genauigkeit zu bestimmen. Zu den wichtigsten GNSS-Systemen gehören das amerikanische in den 70er Jahren entwickelte NAVSTAR GPS (Global Positioning System), das russische GLONASS, das europäische Galileo und das chinesische BeiDou.
\subsection{Grundlegendes Funktionsprinzip}
\label{subsec:gnss_funktionsprinzip}
GNSS-Empfänger (in der Abbildung \ref{fig:gnss_simplified} rot dargestellt) nutzen die Signale von mindestens drei Satelliten, um die dreidimensionale Position (Breiten- und Längengrad sowie Höhe) zu berechnen. Der vierte Satellit wird benötigt, um die genaue Zeitdifferenz zwischen der Satellitenuhr und der Empfängeruhr zu bestimmen, da diese nicht exakt synchronisiert sind. Dabei wird die Laufzeit der Signale vom Satelliten zum Empfänger gemessen, wodurch die Entfernung zu jedem Satelliten bestimmt werden kann.
Jeder GNSS-Satellit sendet dazu seine genaue Sendezeit. Beim Eintreffen des Signals vergleicht der Empfänger diese mit seiner eigenen Zeit und berechnet aus der Zeitdifferenz die Entfernung $s$ zum jeweiligen Satelliten.
Aus diesen Entfernungen lassen sich um die Satelliten gedanklich Kugeln konstruieren, deren gemeinsamer Schnittpunkt (es gibt zwei, jedoch ist einer irrelevant) im dreidimensionalen Raum die Position des Empfängers darstellt.
\\

\begin{figure}[H]
    \centering
\begin{tikzpicture}[scale=0.7]

% Erd-Ausschnitt mit Schattierung
\shade[ball color=blue!50, opacity=0.8]
(-3,-3) arc[start angle=180, end angle=0, radius=3] -- (3,-3) -- cycle;
\draw[thick] (-3,-3) arc[start angle=180, end angle=0, radius=3];

% Empfänger auf der Erde
\filldraw[red] (0,0) circle (4pt) node[above right] {Empfänger};

% Satelliten
\filldraw[fill=gray!30, draw=gray] (-4,3) circle (3pt) node[above] {Satellit 1};
\filldraw[fill=gray!30, draw=gray] (4,3) circle (3pt) node[above] {Satellit 3};
\filldraw[fill=gray!30, draw=gray] (0,5) circle (3pt) node[above] {Satellit 2};

% Abstandskreise (vereinfacht 2D statt Kugeln)
\draw[dashed] (-4,3) circle (5);
\draw[dashed] (4,3) circle (5);
\draw[dashed] (0,5) circle (5);

% Signallinien
\draw[->] (-4,3) -- (0,0) node [midway, above ] {$s_1$};
\draw[->] (4,3) -- (0,0) node [midway, above ] {$s_3$};
\draw[->] (0,5) -- (0,0) node [midway, right] {$s_2$};

\draw (0,-1) node[below] {Erdoberfläche};

\end{tikzpicture}
    \caption{Vereinfachte Darstellung der GNSS-Satelliten und des Empfängers}
    \label{fig:gnss_simplified}
\end{figure}
\newpage
\subsection{Layout}
\label{subsec:gnss_layout}

Bei der Integration eines GNSS-Empfängers auf einer Leiterplatte sind mehrere wichtige Layout-Aspekte zu beachten, um eine optimale Signalqualität und Empfangsleistung zu gewährleisten:
\begin{itemize}
    \item \textbf{Platzierung}: Störquellen wie digitale Schaltungen oder Hochfrequenzkomponenten sollten von der GNSS-Antenne und dem Empfänger (Insbesondere dem Verbindungspfad) getrennt werden, um elektromagnetische Interferenzen zu minimieren. 
    \item \textbf{Leiterbahnlänge}: Die Verbindung zwischen der Antenne und dem GNSS-Empfänger sollte so kurz wie möglich gehalten werden, um Signalverluste und Verzerrungen zu reduzieren. Ergänzend ist es sinnvoll, eine 50-Ohm-impedanzangepasste Leitung zu verwenden.
    \item \textbf{Massefläche}: Eine gute Masseverbindung und Abschirmung (wird durch Vias realisiert) der GNSS-Schaltung ist entscheidend, um Störungen zu minimieren und die Signalqualität zu verbessern. Es ist empfohlen, die GNSS-Masse von der digitalen Masse zu trennen und nur an einem Punkt zu verbinden.
\end{itemize}
Wie bei den bereits in der Sektion \ref{sec:abwaertswandler} beschriebenen Layoutrichtlinien für den Abwärtswandler ist es ratsam, die Layout-Empfehlungen als auch die Bauteilempfehlungen des Herstellers des GNSS-Empfängers zu befolgen, da diese spezifische Hinweise zur optimalen Integration des Bauteils enthalten.
\parencite{AltiumGPS}

\chapter{Software}
\label{ch:software}
\section{STM32CubeIDE}
\label{sec:stm32cubeide}
STM32CubeIDE ist eine integrierte Entwicklungsumgebung (IDE) von STMicroelectronics, die speziell für die Entwicklung von Anwendungen auf STM32-Mikrocontrollern entwickelt wurde. Sie kombiniert den STM32CubeMX-Konfigurationsgenerator mit der Eclipse-basierten IDE, um eine Plattform für die Softwareentwicklung bereitzustellen.
\\ 
Die Hauptfunktionen von STM32CubeIDE umfassen:
\begin{itemize}
    \item \textbf{Konfiguration}: Der integrierte Konfigurator STM32CubeMX ermöglicht die grafische Konfiguration von Peripheriegeräten, Middleware und Pinbelegungen, um automatisch Code zu generieren, der als Ausgangspunkt für die weiter Entwicklung dient.
    \item \textbf{Code-Editor}: Der Code-Editor basiert auf Eclipse und ermöglicht die Bearbeitung von C/C++-Code mit den üblichen Funktionen.
    \item \textbf{Debugging-Tools}: STM32CubeIDE unterstützt verschiedene Debugging-Tools um die Fehlersuche von Anwendungen zu erleichtern, was insbesondere bei selbstentwickelten Platinen hilfreich ist.
\end{itemize}

\section{Treiberentwicklung}
\label{sec:treiberentwicklung}
Um mit den Peripheriegeräten wie IMU, Flash und PWM Driver der Platine über I2C beziehungsweise SPI kommunizieren zu können, müssen zunächst die entsprechenden Treiber entwickelt werden. Ein Treiber ist eine Softwarekomponente, die die Kommunikation zwischen Hardware und Anwendungssoftware ermöglicht. Er konfiguriert zu Beginn die Peripheriegeräte, um die gewünschten Funktionen zu aktivieren, und stellt intern Funktionen bereit, um Daten aus den Registern der Peripherie zu lesen und hineinzuschreiben.
\\
Dabei ist eine Trennung in ein Header File und eine Source File sinnvoll, um eine strukturierte Schnittstelle zu schaffen. Im Header File werden die Funktionen deklariert, die von der Anwendungssoftware aufgerufen werden können, während im Source File die eigentliche Implementierung dieser Funktionen erfolgt. Die Funktionen sollten so gestaltet sein, dass sie die Interaktion mit den Peripheriegeräten dementsprechend abstrahieren, dass die Anwendungssoftware beispielhaft nicht direkt mit den Registeradressen oder der I2C/SPI-Kommunikation umgehen muss, sondern stattdessen einfache Funktionen wie \texttt{read\_acc\_data()} oder \texttt{write\_flash()} aufrufen kann und die Low-Level-Aufgaben vom Treiber übernommen werden.
\\
Die Entwicklung der Treiber erfordert ein umfassendes Verständnis der Spezifikationen der Peripheriegeräte, insbesondere der Registerstruktur, der Kommunikationsprotokolle und der erforderlichen Initialisierungsschritte. Für diese Arbeit hat sich die Verwendung von KI basierten Systemen als sehr hilfreich erwiesen, um schneller Informationen und Abläufe aus Datenblättern zu extrahieren.

\chapter{Lineare Regelungstechnik}
\label{ch:regelungstechnik}

% Anmerkung: Das ist zu nahe an der Anwendung dran und gehört abgeändert sodass ein Überblick über Regelungstechnik gegeben wird 
% Welches System liegt vor nichtlinear linear zeitinvariant zeitvariant etc. 
% Welche teile eines Regelkreises gibt es allgemein
% Welche Regelungsstrategien gibt es allgemein

Dieses Kapitel basiert in großen Teilen auf der Arbeit von \textcite{DataDrivenScience}, und soll einen kompakten Überblick über die für diese Arbeit relevanten Konzepte der linearen Regelungstechnik geben. 
% Um die Lage und Position der Rakete zu bestimmen, messen die auf der Platine integrierten Sensoren (IMU, Barometer, Magnetometer) und GNSS die physikalischen Größen. Diese Messwerte werden in einem Sensorfusion-Algorithmus (Erweiteter-Kalman-Filter, siehe Abschnitt \ref{sec:kalman_filter})kombiniert und mit einer durch physikalische Modelle getroffene Vorhersage des Systemzustands abgeglichen, um eine genaue Schätzung der aktuellen Lage und Position zu erhalten.

% \section{Überblick}
% \label{subsec:regelungstechnik_ueberblick}
% Das Ziel dieses Abschnitts ist es, einen Überblick über die für diese Arbeit relevanten Konzepte der linearen Regelungstechnik zu geben. Dabei werden die grundlegenden Prinzipien und Methoden vorgestellt um ein System zu modellieren und zu regeln.
% \\

\begin{wrapfigure}
{r}{0.4\textwidth}
\vspace{-20pt}
  % {r} = rechtsbündig platzieren
  % Alternativen: {l} = links, {i} = innen (bei zweiseitigem Druck), {o} = außen
  % 0.4\textwidth = Gesamtbreite inkl. Abstand zum Text
  \centering
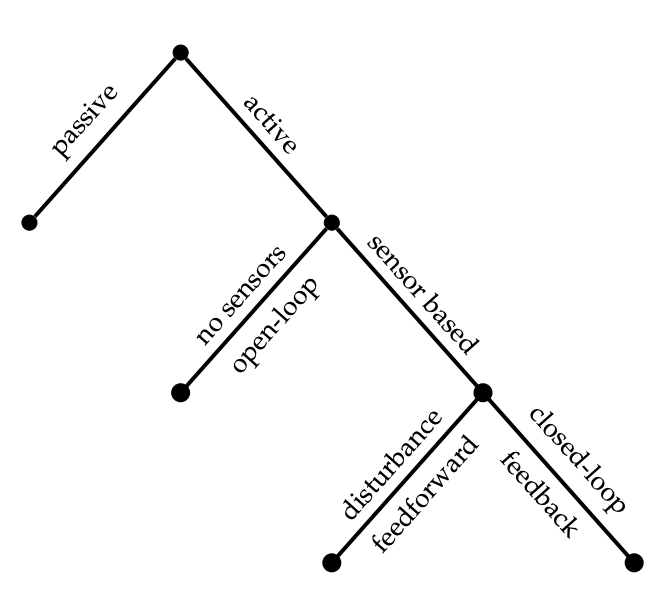
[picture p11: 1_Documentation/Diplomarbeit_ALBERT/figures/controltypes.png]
        
        \caption{Arten von Systemsteuerung \parencite{DataDrivenScience}}
        \label{fig:passive_vs_aktive_steuerung}
  % Bildbreite etwas kleiner als wrapfigure-Breite (Abstand zum Text)   
  \vspace{-10pt}
\end{wrapfigure}

Es gibt verschiedene Wege ein System zu steuern, nach der Einteilung von \textcite{DataDrivenScience} in Abbildung \ref{fig:passive_vs_aktive_steuerung} lassen sich wird zwischen passiver und aktiver Steuerung unterschieden. Passive Steuerungen zeigen keine Reaktion auf Veränderungen und es muss keine Energie aufgewendet werden, Beispiele sind etwa aerodynamische Stabilisatoren an Flugzeugen. 
\\
Welche wiederum sensorbasierte und nicht-sensorbasierte Steuerung umfassen. In der sensorbasierten Steuerung wird zwischen offenen und geschlossenen Regelkreisen unterschieden.
\\
Die Regelung (Closed-Loop Feedback) hat den Vorteil, dass durch die Rückkopplung der Regelgröße auf die Führungsgröße die Abweichung vom Sollwert erkannt und korrigiert werden kann. 
\\
Des Weiteren ist es möglich instabile Systeme zu stabilisieren, auf externe Störungen zu reagieren und unerwartete Veränderungen im System zu kompensieren.

Die Rakete stellt ein dynamisches System mit stark gekoppelten und nichtlinearen Bewegungen dar. Für eine stabile Fluglage und die Einhaltung der gewünschten Flugbahn ist daher eine geeignete Regelung erforderlich. In diesem Kapitel werden die dafür notwendigen Grundlagen der Regelungstechnik sowie die im weiteren Verlauf verwendeten Verfahren vorgestellt. 
\section{Geschlossener Regelkreis}
\label{sec:regelkreis}
In Abbildung \ref{fig:standard_regelkreis} ist ein Standard-Regelkreis dargestellt, welcher die grundlegenden Komponenten eines Regelungssystems zeigt: Regler (Controller), Regelstrecke (System) und Messung. Die Führungsgröße (Reference) $\mathbf{w_r}$ repräsentiert den gewünschten Sollwert und wird mit der gemessenen Regelgröße $\mathbf{y_m}$ verglichen, um die Regelabweichung $\mathbf{e}$ zu bestimmen. Dem Regler wird die Regeldifferenz $\mathbf{e}$ übergeben, welcher daraufhin die Stellgröße $\mathbf{u}$ berechnet und so die Regelstrecke beeinflusst. Die Regelstrecke stellt das zu regelnde System dar, welches auf die Stellgröße $\mathbf{u}$ und Störgröße (Disturbance) $\mathbf{w_d}$ mit der Regelgröße $\mathbf{x}$ reagiert. Diese Regelgröße wird durch eine von Messrauschen (Noise) $\mathbf{w_n}$ behaftete Messung ermittelt und als gemessene Regelgröße $\mathbf{y}$ zurückgeführt, um den Regelkreis zu schließen.
\begin{figure}[H]
    \centering
\tikzstyle{block} = [draw, fill=blue!15, rectangle, 
    minimum height=3em, minimum width=6em]
\tikzstyle{sum} = [draw, fill=blue!15, circle, node distance=1cm]
\tikzstyle{input} = [coordinate]
\tikzstyle{output} = [coordinate]
\tikzstyle{pinstyle} = [pin edge={to-,thin,black}]

\begin{tikzpicture}[auto, node distance=2cm,>=latex']

    \node [input, name=input] {};
    \node [sum, right of=input] (sum) {};
    \node [block, right of=sum] (controller) {Regler};
    \node [block, right of=controller, pin={[pinstyle]above:$w_d$},
            node distance=4cm] (system) {Regelstrecke};
    % We draw an edge between the controller and system block to 
    % calculate the coordinate u. We need it to place the measurement block. 
    \draw [->] (controller) -- node[name=u] {$u$} (system);
    \node [output, right of=system] (output) {};
    \node [block, below of=u, pin={[pinstyle]below:$w_n$}, node distance=2cm] (measurements) {Messung};

    % Once the nodes are placed, connecting them is easy. 
    \draw [draw,->] (input) -- node {$w_r$} (sum);
    \draw [->] (sum) -- node {$e$} (controller);
    \draw [->] (system) -- node [name=x] {$x$}(output);
    \draw [->] (x) |- (measurements);
    \draw [->] (measurements) -| node[pos=0.99] {$-$} 
        node [near end] {$y$} (sum);

\end{tikzpicture}
    \caption{Standard-Regelkreis }
    \label{fig:standard_regelkreis}
\end{figure}

So kann die Regelstrecke und die Messung mathematisch wie folgt beschrieben werden:
\begin{equation}
    \dot{\mathbf{x}} = \mathbf{f}(\mathbf{x},\mathbf{u},\mathbf{w}_d)
\end{equation}
\begin{equation}
    \mathbf{y} = \mathbf{h}(\mathbf{x},\mathbf{u},\mathbf{w}_n)
\end{equation}
Das Ziel des Reglers ist es nun eine optimale Stellgröße $\mathbf{u}$ zu berechnen um die Kostenfunktion $J$ zu minimieren:
\begin{equation}
    \mathbf{u} = \mathbf{k}(\mathbf{y},\hat{\mathbf{x}}, \mathbf{w}_r)
\end{equation}
\begin{equation}
    J \triangleq J(\mathbf{x},\mathbf{u},\mathbf{w}_r)
\end{equation}
Wobei $\hat{\mathbf{x}}$ die Schätzung des Systemzustands durch einen Zustandsschätzer (z.B. Kalman-Filter) darstellt.

\section{Linearisierung}
\label{sec:linearisierung}
Die Anwendung vieler Regelungsverfahren setzt ein lineares Systemmodell voraus, in der Praxis sind die meisten Systeme jedoch nichtlinear. Um dennoch lineare Regelungsverfahren anwenden zu können, kann das nichtlineare System um einen oder mehrere Arbeitspunkte linearisiert werden. 
\\Im Folgenden werden die Störgrößen zur Vereinfachung vorübergehend vernachlässigt.
\\\\
Hierzu werden die nichtlinearen Systemgleichungen an einem Arbeitspunkt $(\bar{\mathbf{x}}, \bar{\mathbf{u}})$ an dem die Ableitungen der Systemgrößen null sind, mittels Taylor-Entwicklung approximiert. Für kleine Abweichungen $\Delta \mathbf{x}$ und $\Delta \mathbf{u}$ um den Arbeitspunkt gilt somit:
\begin{equation}
\mathbf{f}(\bar{\mathbf{x}} + \Delta \mathbf{x}, \bar{\mathbf{u}} + \Delta \mathbf{u}) = \mathbf{f}(\bar{\mathbf{x}}, \bar{\mathbf{u}}) + \underbrace{\left. \frac{\partial \mathbf{f}}{\partial \mathbf{x}} \right|_{(\bar{\mathbf{x}}, \bar{\mathbf{u}})}}_{\mathbf{A}} \cdot \Delta \mathbf{x} + \underbrace{\left. \frac{\partial \mathbf{f}}{\partial \mathbf{u}} \right|_{(\bar{\mathbf{x}}, \bar{\mathbf{u}})}}_{\mathbf{B}} \cdot \Delta \mathbf{u} + \cdots
\end{equation}

\begin{equation} 
\mathbf{h}(\bar{\mathbf{x}} + \Delta \mathbf{x}, \bar{\mathbf{u}} + \Delta \mathbf{u}) = \mathbf{h}(\bar{\mathbf{x}}, \bar{\mathbf{u}}) + \underbrace{\left. \frac{\partial \mathbf{h}}{\partial \mathbf{x}} \right|_{(\bar{\mathbf{x}}, \bar{\mathbf{u}})}}_{\mathbf{C}} \cdot \Delta \mathbf{x} + \underbrace{\left. \frac{\partial \mathbf{h}}{\partial \mathbf{u}} \right|_{(\bar{\mathbf{x}}, \bar{\mathbf{u}})}}_{\mathbf{D}} \cdot \Delta \mathbf{u} + \cdots
\end{equation}
Nun können bei einer Verschiebung des Koordinatensystems auf den Arbeitspunkt $(\bar{\mathbf{x}}, \bar{\mathbf{u}})$ die Differentialgleichungen mit den Jacobi-Matrizen siehe \ref{subsec:jacobi_matrizen} $\mathbf{A}$, $\mathbf{B}$, $\mathbf{C}$ und $\mathbf{D}$ wie folgt beschrieben werden:
\begin{equation}
  \dot{\mathbf{x}} = \mathbf{A} \cdot  \mathbf{x} + \mathbf{B} \cdot  \mathbf{u}
\end{equation}
\begin{equation}
     \mathbf{y} = \mathbf{C} \cdot  \mathbf{x} + \mathbf{D} \cdot  \mathbf{u} 
\end{equation}
\subsection{Jacobi Matrizen}
\label{subsec:jacobi_matrizen}
Die Jacobi-Matrix ist eine Matrix, die die partiellen Ableitungen einer Matrix nach ihren Variablen enthält. Sie stellt die lokale Steigung einer nichtlinearen Funktion in mehreren Richtungen dar.
\\
Für eine Funktion ${f}({x})$ mit $m$ Ausgabekomponenten (Zeilen) und $n$ Eingabekomponenten (Spalten) ist die Jacobi-Matrix definiert als:
\begin{equation}
    \mathbf{J} = \begin{bmatrix}
    \frac{\partial f_1}{\partial x_1}  & \cdots & \frac{\partial f_1}{\partial x_n} \\
    
    \vdots  & \ddots & \vdots \\
    \frac{\partial f_m}{\partial x_1} &  \cdots & \frac{\partial f_m}{\partial x_n}
    \end{bmatrix}
\end{equation}

\section{Steuerbarkeit}
\label{sec:steuerbarkeit}
Die Steuerbarkeit (Controllability) eines Systems beschreibt die Fähigkeit, den Systemzustand durch geeignete Wahl der Stellgröße $\mathbf{u}$ zu einem stabilen Endzustand zu steuern. Dies kann durch Rückführung der Stellgröße $\mathbf{u}$ auf den Systemzustand $\mathbf{x}$ über die Matrix $\mathbf{K}$ erreicht werden:
\begin{equation}
    \mathbf{u} = -\mathbf{K} \cdot \mathbf{x}
\end{equation}
durch einsetzen in die Systemgleichung ergibt sich:
\begin{equation}
    \dot{\mathbf{x}} = \mathbf{A} \cdot  \mathbf{x} + \mathbf{B} \cdot  (-\mathbf{K} \cdot \mathbf{x}) = (\mathbf{A} - \mathbf{B} \cdot \mathbf{K}) \cdot  \mathbf{x}
\end{equation}
Ein stabiler Systemzustand ist gegeben, wenn alle Eigenwerte der Systemmatrix $(\mathbf{A} - \mathbf{B} \cdot \mathbf{K})$ negative Realteile haben.
\begin{figure}[H]
    \centering
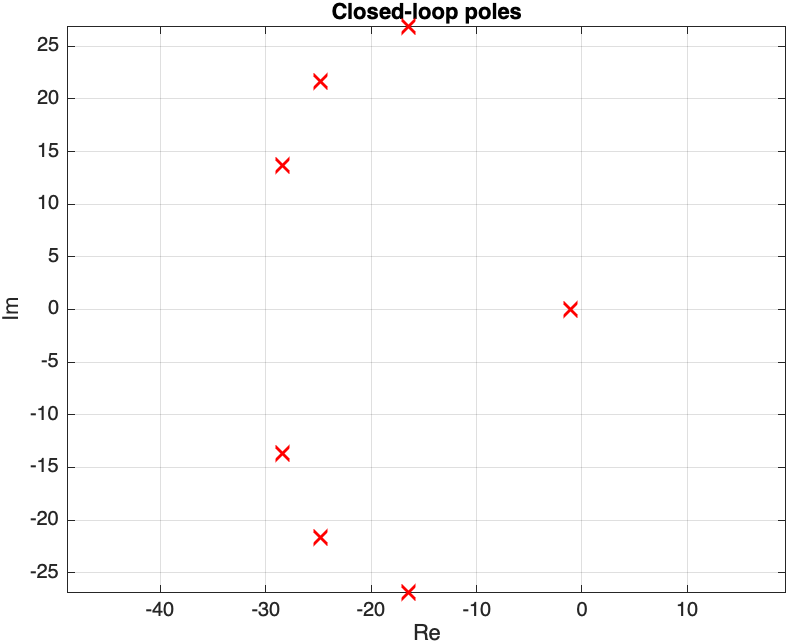
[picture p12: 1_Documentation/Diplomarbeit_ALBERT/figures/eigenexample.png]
    
    \caption{Eigenwerte eines stabilen geschlossenen Regelkreises}
    \label{fig:eigenwerte_geschlossener_regelkreis}
\end{figure}
In Matlab können die Eigenwerte einer Matrix mit der Funktion \texttt{eig()} berechnet werden.
Ob ein System steuerbar ist, kann durch die Steuerbarkeitsmatrix $\mathcal{C} = [\mathbf{B}, \mathbf{A} \cdot \mathbf{B}, \mathbf{A}^2 \cdot \mathbf{B}, ..., \mathbf{A}^{n} \cdot \mathbf{B}]$ überprüft werden, wenn diese Matrix vollen Rang sprich $\mathrm{rank}(\mathcal{C}) = n$ hat, ist das System steuerbar. Hierzu kann in Matlab die Funktion \texttt{ctrb(A,B)} welche die Steuerbarkeitsmatrix berechnet und die Funktion \texttt{rank()} die den Rang von $\mathcal{C}$ überprüft verwendet werden. \parencite{DataDrivenScience}

\section{Beobachtbarkeit}
\label{sec:beobachtbarkeit}
Die Beobachtbarkeit (Observability) eines Systems beschreibt die Fähigkeit, den Systemzustand $\mathbf{x}$ aus den Messungen der Regelgröße $\mathbf{y}$ zu rekonstruieren. Mathematisch gesehen sind sich Steuerbarkeit und Beobachtbarkeit sehr ähnlich, was bereits darauf hindeutet, dass auch zwischen LQR und Kalman-Filter eine enge Verbindung besteht. Ein System ist genau dann beobachtbar, wenn die Beobachtbarkeitsmatrix $\mathcal{O}=[\mathbf{C}, \mathbf{A} \cdot \mathbf{C}, \mathbf{A}^2 \cdot \mathbf{C}, ..., \mathbf{A}^{n} \cdot \mathbf{C}]$ vollen Rang $n$ hat. In Matlab kann die Beobachtbarkeitsmatrix mit der Funktion \texttt{obsv(A,C)} berechnet werden. \parencite{DataDrivenScience}

\section{Linear Quadratic Regulator (LQR)}
\label{sec:lqr_regler}
Zur Auslegung eines geeigneten Zustandsreglers wird ein Linear Quadratic Regulator (LQR) verwendet. 
Die Grundidee des LQR besteht darin, eine Zustandsrückführung zu bestimmen, die das System stabilisiert und 
gleichzeitig ein definiertes Optimierungskriterium erfüllt. Dabei wird ein Kompromiss zwischen einer möglichst 
schnellen Annäherung an den Sollzustand und einem möglichst geringen Stellaufwand gesucht. Der Name setzt sich aus den Begriffen \textit{linear}, da der Regler linear ist $\mathbf{u} = -\mathbf{K} \mathbf{x}$, \textit{"quadratic"}, da die Kostenfunktion $J$ quadratisch ist, und \textit{regulator} zusammen, da es sich um einen Regler handelt.

Unter der Voraussetzung, dass das System steuerbar ist und der vollständige Zustand $\mathbf{x}$ beobachtbar ist, 
kann eine optimale Rückführungsmatrix $\mathbf{K}$ bestimmt werden. Optimal bedeutet hierbei, dass die folgende 
Kostenfunktion minimiert wird:

\begin{equation}
J = \int_{0}^{\infty} \left( \mathbf{x}^{T} \mathbf{Q} \mathbf{x} + \mathbf{u}^{T} \mathbf{R} \mathbf{u} \right) dt
\end{equation}

Die Matrizen $\mathbf{Q}$ und $\mathbf{R}$ dienen als Gewichtungsmatrizen und legen fest, wie stark 
Zustandsabweichungen beziehungsweise Stellaufwand im Optimierungskriterium berücksichtigt werden. 
Während große Einträge in $\mathbf{Q}$ eine stärkere Bestrafung von Zustandsabweichungen bewirken, 
führen große Einträge in $\mathbf{R}$ zu einer stärkeren Einschränkung der Stellgrößen.

Im Gegensatz zur direkten Polvorgabe, bei der die Polstellen gezielt gewählt werden, ergibt sich beim LQR 
die Lage der geschlossenen Polstellen aus der Minimierung der Kostenfunktion. Dadurch entsteht ein sinnvoller Kompromiss zwischen Dynamik und Stellaufwand.
\parencite{DataDrivenScience}

\subsection{Lösung der algebraischen Riccati-Gleichung}
\label{subsec:riccati_gleichung}
Die optimale Rückführungsmatrix $\mathbf{K}$ wird durch die Lösung der algebraischen Riccati-Gleichung 
bestimmt. In Matlab kann diese mit der Funktion \texttt{lqr(A,B,Q,R)} berechnet werden.
\\
Im Folgenden soll die algebraische Riccati-Gleichung der Kostenfunktion $J$ dem Erkenntnisgewinn halber gelöst werden, um die optimale Rückführungsmatrix $\mathbf{K}$ zu bestimmen.
\begin{equation}
J = \int_{0}^{t_f} \underbrace{\frac{1}{2} \left( \mathbf{x}^{T} \mathbf{Q} \mathbf{x} + \mathbf{u}^{T} \mathbf{R} \mathbf{u} \right)}_{\text{Langragian }\mathcal{L}} dt 
+ \underbrace{\frac{1}{2}\mathbf{x}_{t_f}^{T} \mathbf{Q}_f \mathbf{x}_{t_f}}_{\text{Terminal cost}}
\end{equation}
In diesem Punkt wird die Kostenfunktion um eine Terminal Cost erweitert, welche die Kosten am Ende der Regelung zum Zeitpunkt $t_f$ berücksichtigt. Außerdem wird die Kostenfunktion um den Faktor $\frac{1}{2}$ skaliert, um die Ableitungen zu vereinfachen.
\begin{equation}
J_{aug} = \int_{0}^{t_f} \frac{1}{2} \left( \mathbf{x}^{T} \mathbf{Q} \mathbf{x} + \mathbf{u}^{T} \mathbf{R} \mathbf{u} \right) + \mathbf{\lambda}^T (\mathbf{Ax} + \mathbf{Bu} - \dot{\mathbf{x}}) dt 
+ {\frac{1}{2}\mathbf{x}_{t_f}^{T} \mathbf{Q}_f \mathbf{x}_{t_f}}
\end{equation}
Auf Basis des Zusammenhangs $\dot{\mathbf{x}} = \mathbf{Ax} + \mathbf{B} \mathbf{u}$ sind $\mathbf{x}$ und $\mathbf{u}$ nicht unabhängig, weshalb die Kostenfunktion um die Lagrange-Multiplikatoren $\mathbf{\lambda}$ erweitert (augmented) wird, um diesen Zusammenhang zu berücksichtigen.
\begin{equation}
    \delta J_{\text{aug}} =
\int_{0}^{t_f}
\left[
\frac{\partial \mathcal{L}}{\partial \mathbf{x}}\,\delta \mathbf{x}
+
\frac{\partial \mathcal{L}}{\partial \mathbf{u}}\,\delta \mathbf{u}
+
\lambda^{T} \mathbf{A}\,\delta \mathbf{x}
+
\lambda^{T} \mathbf{B}\,\delta \mathbf{u}
-
\lambda^{T}\,\delta \dot{\mathbf{x}}
\right] dt
+
\mathbf{Q}_f\,\mathbf{x}_{t_f}\,\delta \mathbf{x}_{t_f}.
\end{equation}

Die partiellen Ableitungen der Lagrange-Funktion $\mathcal{L}$ nach $\mathbf{x}$ und $\mathbf{u}$ ergeben sich zu:
\begin{equation}
  \frac{\partial \mathcal{L}}{\partial \mathbf{x}} = \mathbf{x}^{T} \mathbf{Q}
\quad \text{and} \quad
\frac{\partial \mathcal{L}}{\partial \mathbf{u}} = \mathbf{u}^{T} \mathbf{R} .  
\end{equation}

Der Term $\lambda^{T}\,\delta \dot{\mathbf{x}}$ kann durch partielle Integration umgeformt werden:
\begin{equation}
- \int_{0}^{t_f} \lambda^{T}\,\delta \dot{\mathbf{x}}\, dt
=
- \lambda^{T}_{t_f}\,\delta \mathbf{x}_{t_f}
+ \lambda^{T}_{0}\,\delta \mathbf{x}_{0}
+ \int_{0}^{t_f} \dot{\lambda}^{T}\,\delta \mathbf{x}\, dt .
\end{equation}
Dabei muss der Term $\lambda^{T}_{0}\,\delta \mathbf{x}_{0}$ nicht berücksichtigt werden, da die Anfangsbedingung $x(0)=x_0$ fest vorgegeben ist, und somit $\delta \mathbf{x}_{0} = 0$ gilt.
\\
Durch einsetzen ergibt sich die Variation der augmentierten Kostenfunktion zu:
\begin{align}
\delta J_{\text{aug}} &=
\int_{0}^{t_f}
\left(\mathbf{x}^{T}\mathbf{Q} + \lambda^{T}\mathbf{A} + \dot{\lambda}^{T}\right)\delta \mathbf{x}\, dt
+
\int_{0}^{t_f}
\left(\mathbf{u}^{T}\mathbf{R} + \lambda^{T}\mathbf{B}\right)\delta \mathbf{u}\, dt  
+
\left(\mathbf{x}_{t_f}^{T}\mathbf{Q}_f - \lambda^{T}_{t_f}\right)\delta \mathbf{x}_{t_f}
\end{align}
Zur Minimierung der Kostenfunktion muss die Variation $\delta J_{\text{aug}}$ für alle möglichen Variationen $\delta \mathbf{x}$, $\delta \mathbf{u}$ und $\delta \mathbf{x}_{t_f}$ gleich null sein. Dies führt zu den folgenden Gleichungen:
\begin{align}
\mathbf{x}^{T}\mathbf{Q} + \lambda^{T}\mathbf{A} + \dot{\lambda}^{T} &= 0  \\
\mathbf{u}^{T}\mathbf{R} + \lambda^{T}\mathbf{B} &= 0  \\
\mathbf{x}_{t_f}^{T}\mathbf{Q}_f - \lambda^{T}_{t_f} &= 0
\end{align}
Diese Gleichungen können nun verwendet werden, um die optimale Rückführungsmatrix $\mathbf{K}$ zu bestimmen. Zunächst wird die zweite Gleichung nach $\mathbf{u}$ umgestellt:
\begin{equation}
\mathbf{u} = \mathbf{-R}^{-1}\mathbf{B}^{T}\lambda 
\end{equation}
Es wird angenommen, dass die Kostatenvariable $\lambda$ proportional zum Systemzustand $x$ ist, mit der Proportionalitätskonstante $P$, welche eine symmetrische Matrix ist. 
\begin{equation}
\lambda = \mathbf{Px}
\end{equation}
Durch einsetzen in die Gleichung für $\lambda = \mathbf{Px}$ und $\dot{\mathbf{x}} = \mathbf{Ax} + \mathbf{Bu}$ ergibt sich:
\begin{equation}
\dot{\mathbf{P}}\mathbf{x} + \mathbf{P}(\mathbf{Ax} + \mathbf{Bu}) + \mathbf{Q}\mathbf{x} + \mathbf{A}^{T}\mathbf{Px} = 0 
\end{equation}

Durch Einsetzen von $\mathbf{u} = \mathbf{-R}^{-1}\mathbf{B}^{T}\mathbf{Px}$ ergibt sich die folgende Gleichung:

\begin{equation}
\dot{\mathbf{P}}\mathbf{x} + \mathbf{P}\mathbf{Ax} + \mathbf{A}^{T}\mathbf{Px} - \mathbf{P}\mathbf{B}\mathbf{R}^{-1}\mathbf{B}^{T}\mathbf{Px} + \mathbf{Q}\mathbf{x} = 0
\end{equation}
Diese Gleichung muss für alle $\mathbf{x}$ erfüllt sein und kann daher auch als Matrixgleichung geschrieben werden. Unter Vernachlässigung der Terminal Cost und für $t \to \infty$ verschwindet der Term $\dot{\mathbf{P}}$, und man erhält die algebraische Riccati-Gleichung:

\begin{equation}
\mathbf{PA} + \mathbf{A}^{T}\mathbf{P} - \mathbf{P}\mathbf{B}\mathbf{R}^{-1}\mathbf{B}^{T}\mathbf{P} + \mathbf{Q} = 0.
\end{equation}
Durch lösen dieser Gleichung nach $\mathbf{P}$ und einsetzen in die Gleichung für $\mathbf{u}$ ergibt sich die optimale Rückführungsmatrix $\mathbf{K}$ zu:
\begin{equation}
\mathbf{K} = \mathbf{R}^{-1}\mathbf{B}^{T}\mathbf{P}
\end{equation}
Ein intuitiver Ansatz ist die Frage wie schlimm der Zustand $\mathbf{P}$ aktuell ist, dieser wird auf die Matrix $\mathbf{B}$ projiziert, um zu bestimmen wie stark die Stellgröße $\mathbf{u}$ auf diesen Zustand einwirken kann, und schließlich wird mit der Inversen von $\mathbf{R}$ gewichtet, um den Stellaufwand zu berücksichtigen.
\parencite{DataDrivenScience}

\section{Kalman-Filter}
\label{sec:kalman_filter}
Das Kalman-Filter ist ein mathematisches Verfahren zur iterativen Schätzung des Zustands eines linearen Systems aus einer Reihe von verrauschten Messungen von indirekten Systemgrößen. Der große Vorteil im Vergleich zu anderen Filtermethoden liegt in der Fähigkeit, in Echtzeit zu arbeiten, was die Anwendung in Inertialnavigationssystemen in Flugzeugen und Raketen ermöglicht.
Es wurde ursprünglich von Rudolf E. Kálmán, Richard S. Bucy und Ruslan L. Stratonovich in den 1960er Jahren entwickelt und fand bereits kurz darauf in den Apollo-Missionen der NASA Anwendung zur Navigation, dieser schnelle Sprung von der mathematischen Forschung zur ingenieurstechnischen Anwendung ist außergewöhnlich und zeigt die Effektivität des Verfahrens.
\\
Um den Schätzwert des Systems zu beschreiben werden im Gegensatz zu einfacheren Filtermethoden wie dem gleitenden Mittelwert mehrdimensionale Normalverteilungen verwendet. So können auch die Zusammenhänge von Schätzfehlern verschiedener Systemgrößen berücksichtigt werden um in jedem Zeitschritt eine optimale Schätzung zu erhalten.
\\
Eine Anwendung eines Kalman-Filters macht dann Sinn, wenn erstens eine zugrundeliegende Systemdynamik (physikalische Gesetze) modelliert werden kann und somit eine Vorhersage des Systemzustands möglich ist und zweitens eine direkte Messung der Systemgrößen nicht möglich oder mit Unsicherheiten behaftet ist. Das Kalman-Filter kombiniert diese beiden Informationsquellen optimal um so eine genauere Vorhersage des Systemzustands zu erhalten.
\\
Im Folgenden soll der Kalman-Filter in seiner in der Literatur am häufigsten beschriebenen Form vorgestellt werden: in diskreter Zeit und für lineare Systeme. Der Kalman-Filter wird deshalb detaillierter beschrieben, da eine intuitivere Betrachtung im Vergleich zum Ablauf eines LQR-Controllers möglich ist. Später wird im Rahmen des Kapitels \ref{sec:lqg} auf die spiegelbildartige Verbindung zwischen LQR und Kalman-Filter eingegangen, um die kaum zu übersehende Ähnlichkeit der beiden Verfahren zu verdeutlichen. 
\parencite{Kalman60}
\parencite{DorFuchsKalman}
\parencite{WikipediaKalman}

\subsection{Zustandsraummodellierung}
\label{subsec:zustandsraummodellierung}
Das Kalman-Filter basiert auf einer Zustandsraummodellierung des Systems, dabei wird der Systemzustand zu einem Zeitpunkt $k$ durch einen mehrdimensionalen Vektor $\mathbf{X}_k$ (Zuststandsgleichung) beschrieben, welcher sich aus den Systemgrößen zusammensetzt. Die Dynamik des Systems wird durch die Zustandsübergangsmatrix $\mathbf{F}_k$ beschrieben, welche den Einfluss des vorherigen Zustands $\mathbf{x}_{k-1}$ auf den aktuellen Zustand $\mathbf{x}_k$ modelliert. Um deterministische Steuerungseinflüsse zu berücksichtigen, wird der Steuervektor $\mathbf{u}_k$ mit der Steuerungsmatrix $\mathbf{B}_k$ multipliziert und zum Systemzustand addiert. Zusätzlich wird Prozessrauschen  berücksichtigt, welches die Unsicherheiten im Systemmodell als normalverteilte Zufallsvariable $\mathbf{w}_k$ beschreibt.
\begin{equation}
    \mathbf{x}_k = \mathbf{F}_k \cdot \mathbf{x}_{k-1} + \mathbf{B}_k \cdot \mathbf{u}_k + \mathbf{w}_k
\end{equation}
Beispielhaft hier angeführt eine eindimensionale Bewegung mit konstanter Geschwindigkeit ohne Prozessrauschen, bei der die Position $x_k$ und die Geschwindigkeit $\dot{x}_k$ des Systems den Systemzustand bilden:
\begin{equation}
    \mathbf{x}_k = \begin{bmatrix}
    x_k \\
    \dot{x}_k
    \end{bmatrix}
\end{equation}
Die Zustandsübergangsmatrix $\mathbf{F}_k$ für dieses System lautet:
\begin{equation}
    \mathbf{F}_k = \begin{bmatrix}
    1 & \Delta t \\
    0 & 1
    \end{bmatrix}
\end{equation}
wobei $\Delta t$ die Zeitdifferenz zwischen den Zeitschritten $k-1$ und $k$ ist. In diesem Fall wird kein Steuervektor verwendet, also ist $\mathbf{B}_k \cdot \mathbf{u}_k = 0$.
\\
Man könnte die Zuststandsgleichung nun wie folgt anschreiben:
\begin{equation}
    \begin{bmatrix}
    x_k \\
    \dot{x}_k
    \end{bmatrix} = \begin{bmatrix}
    1 & \Delta t \\
    0 & 1
    \end{bmatrix} \cdot \begin{bmatrix}
    x_{k-1} \\
    \dot{x}_{k-1}
    \end{bmatrix}
     = \begin{bmatrix}
    x_{k-1} + \dot{x}_{k-1} \cdot \Delta t \\
    \dot{x}_{k-1}
    \end{bmatrix}
\end{equation}
\\
\\
Die Beobachtungen der realen Systemgrößen werden durch den Messvektor $\mathbf{z}_k$ beschrieben, welcher sich aus den gemessenen Größen zusammensetzt. Die als linear angenommene Verzerrung zwischen dem Systemzustand und den Messungen wird durch die Beobachtungsmatrix $\mathbf{H}_k$ modelliert, welche den Einfluss des Systemzustands auf die Messungen beschreibt. Zusätzlich wird Messrauschen berücksichtigt, welches die Unsicherheiten in den Messungen als normalverteilte Zufallsvariable $\mathbf{v}_k$ beschreibt.
\begin{equation}
    \mathbf{z}_k = \mathbf{H}_k \cdot \mathbf{x}_k + \mathbf{v}_k
\end{equation}
\\
Die Zustandsgleichungen und die Messgleichungen bilden die Grundlage für den Filteralgorithmus und werden als Zustandsraummodellierung bezeichnet.
\\

\subsection{Vorhersageschritt}
\label{subsec:vorhersageschritt}
Im Vorhersageschritt wird nach der zuvor aufgestellten Zustandsgleichung der vorhergesagte Systemzustand $\mathbf{x}_{k|k-1}$ und die vorhergesagte Kovarianzmatrix\footnote{Kovarianzmatrix - mehrdimensionale Zufallsvariable} $\mathbf{P}_{k|k-1}$ berechnet. Diese Vorhersagen basieren auf dem vorherigen geschätzten Zustand $\mathbf{x}_{k-1}$ und da der Erwartungswert des Prozessrauschens $\mathbf{w}_k$ null ist, wird dieses im Vorhersageschritt nicht berücksichtigt.
\begin{equation}
    \mathbf{x}_{k|k-1} = \mathbf{F}_k \cdot \mathbf{x}_{k-1} + \mathbf{B}_k \cdot \mathbf{u}_k
\end{equation}
In diesem Schritt wird ebenfalls die Kovarianzmatrix $\mathbf{P}_{k|k-1}$ der Schätzfehler aktualisiert, welche die Unsicherheiten in der Schätzung des Systemzustands beschreibt. Dabei wird auf Basis der vorherigen Kovarianzmatrix $\mathbf{P}_{k-1}$ und der Zustandsgleichung sowie der Kovarianzmatrix $\mathbf{Q}_k$ des Prozessrauschens $\mathbf{w}_k$ die neue Kovarianzmatrix berechnet.
\begin{equation}
    \mathbf{P}_{k|k-1} = \mathbf{F}_k \cdot \mathbf{P}_{k-1} \cdot \mathbf{F}_k^T + \mathbf{Q}_k
\end{equation}

\subsection{Korrekturschritt}
\label{subsec:korrekturschritt}
Im Korrekturschritt wird die Vorhersage des Systemzustands $\mathbf{x}_{k|k-1}$ anhand der aktuellen Messungen $\mathbf{z}_k$ angepasst, um eine genauere Schätzung zu erhalten. Dazu wird zunächst der Innovationsvektor $\mathbf{y}_k$ berechnet, welcher die Differenz zwischen den tatsächlichen Messungen und den vorhergesagten Messungen darstellt. Das Messmodell ist hier aufgrund der in der Literatur üblichen Schreibweise als $\mathbf{z}_k$ angeschrieben, wird jedoch im Abschnitt \ref{sec:regelkreis} als $\mathbf{g}(\mathbf{x}_k, \mathbf{u}_k, \mathbf{w}_k)$ bezeichnet, .
\begin{equation}
    \mathbf{y}_k = \mathbf{z}_k - \mathbf{H}_k \cdot \mathbf{x}_{k|k-1}
\end{equation}
\\
Anschließend stellt sich die Frage wie stark die Messdaten gewichtet werden sollen, um die Vorhersage zu korrigieren. Diese Gewichtung wird durch die Kalman-Gain-Matrix $\mathbf{K}_k$ beschrieben, welche auf Basis der vorhergesagten Kovarianzmatrix $\mathbf{P}_{k|k-1}$, der Beobachtungsmatrix $\mathbf{H}_k$ und der Kovarianzmatrix $\mathbf{R}_k$ des Messrauschens $\mathbf{v}_k$ berechnet wird.
\begin{equation}
    \mathbf{K}_k = \frac{\mathbf{P}_{k|k-1} \cdot \mathbf{H}_k^T }{\mathbf{H}_k \cdot \mathbf{P}_{k|k-1} \cdot \mathbf{H}_k^T + \mathbf{R}_k} 
\end{equation}
Mit der Kalman-Gain-Matrix wird nun die Vorhersage des Systemzustands dynamisch korrigiert, um die aktualisierte Schätzung des Systemzustands $\mathbf{x}_k$ zu erhalten.
\begin{equation}
    \mathbf{x}_k = \mathbf{x}_{k|k-1} + \mathbf{K}_k \cdot \mathbf{y}_k
\end{equation}
Abschließend wird die Kovarianzmatrix der Schätzfehler aktualisiert, um die Unsicherheiten in der aktualisierten Schätzung des Systemzustands zu beschreiben. Das Ziel des Filters ist es, diese Unsicherheiten zu minimieren.
\begin{equation}
    \mathbf{P}_k = (\mathbf{I} - \mathbf{K}_k \cdot \mathbf{H}_k) \cdot \mathbf{P}_{k|k-1}
\end{equation}
\subsection{Erweiterter Kalman-Filter}
\label{subsec:erweiterter_kalman_filter}
Der erweiterte Kalman-Filter (EKF) ist eine Erweiterung des klassischen Kalman-Filters, die es ermöglicht, nichtlineare Systeme zu modellieren und zu schätzen. Während der klassische Kalman-Filter auf linearen Zustands- und Messgleichungen basiert, verwendet der EKF eine lokale lineare Approximation dieser Gleichungen.
\\
Hierzu werden die Jacobi-Matrizen der nichtlinearen Funktionen an der
aktuellen Zustandsabschätzung ausgewertet und als 
Matrizen $\mathbf{F}_k$ und $\mathbf{H}_k$ verwendet um Kalman-Gain und Kovarianzmatrix zu berechnen.
\\
\\
Das nichtlineare Zustandsmodell ist gegeben durch
\begin{equation}
\mathbf{x}_k = \mathbf{f}(\mathbf{x}_{k-1}, \mathbf{u}_{k-1}) + \mathbf{w}_{k-1},
\end{equation}
wobei $\mathbf{w}_{k-1}$ das Prozessrauschen beschreibt.
Durch Linearisierung um die letztige Schätzung des Systemzustands
$\hat{\mathbf{x}}_{k-1}$ ergibt sich
\begin{equation}
\mathbf{x}_k \approx \mathbf{f}({\mathbf{x}}_{k-1}, \mathbf{0})
+ \mathbf{F}_k (\mathbf{x}_{k-1} - {\mathbf{x}}_{k|k-1})
+ \mathbf{W}_k \mathbf{w}_{k-1},
\end{equation}
mit den Jacobi-Matrizen
\begin{equation}
\mathbf{F}_k =
\left.\frac{\partial \mathbf{f}}{\partial \mathbf{x}}\right|_{{\mathbf{x}}_{k-1}},
\qquad
\mathbf{W}_k =
\left.\frac{\partial \mathbf{f}}{\partial \mathbf{w}}\right|_{{\mathbf{x}}_{k-1}}
\end{equation}
\\
Das nichtlineare Beobachtungsmodell (Messvektor) lautet
\begin{equation}
\mathbf{z}_k = \mathbf{h}(\mathbf{x}_k) + \mathbf{v}_k
\end{equation}
wobei $\mathbf{v}_k$ das Messrauschen bezeichnet.
\\
Die Linearisierung um die a-priori-Zustandsschätzung
${\mathbf{x}}_{k|k-1}$ führt zu
\begin{equation}
\mathbf{z}_k \approx \mathbf{h}({\mathbf{x}}_{k|k-1}, \mathbf{0})
+ \mathbf{H}_k ({\mathbf{x}}_{k|k-1} - \mathbf{x}_k)
+ \mathbf{V}_k \mathbf{v}_k
\end{equation}
mit den Jacobi-Matrizen
\begin{equation}
\mathbf{H}_k =
\left.\frac{\partial \mathbf{h}}{\partial \mathbf{x}}\right|_{{\mathbf{x}}_{k|k-1}},
\qquad
\mathbf{V}_k =
\left.\frac{\partial \mathbf{h}}{\partial \boldsymbol{\nu}}\right|_{{\mathbf{x}}_{k|k-1}}.
\end{equation}
Für den Vorhersageschritt des EKF ergibt sich somit:
\begin{equation}
   \hat{\mathbf{x}}_{k|k-1} = \mathbf{f}(\hat{\mathbf{x}}_{k-1}, \mathbf{u}_{k-1}) 
\end{equation}
\begin{equation}
    \mathbf{P}_{k|k-1} = \mathbf{F}_k \cdot \mathbf{P}_{k-1} \cdot \mathbf{F}_k^T +   \mathbf{Q}_{k-1} 
\end{equation}
Für den Korrekturschritt des EKF ergibt sich:
\begin{equation}
    \mathbf{y}_k = \mathbf{z}_k - \mathbf{h}(\hat{\mathbf{x}}_{k|k-1}) 
\end{equation}
\begin{equation}
    \mathbf{K}_k =  \frac{\mathbf{P}_{k|k-1} \cdot \mathbf{H}_{k}^T}{  \mathbf{H}_{k} \cdot \mathbf{P}_{k|k-1} \cdot \mathbf{H}_{k}^T +  \mathbf{R}_k }
\end{equation}
\begin{equation}
    \mathbf{P}_k = (\mathbf{I} - \mathbf{K}_k \cdot \mathbf{H}_{k}) \cdot \mathbf{P}_{k|k-1}
\end{equation}  
\begin{equation}
    \hat{\mathbf{x}}_k = \hat{\mathbf{x}}_{k|k-1} + \mathbf{K}_k \cdot \mathbf{y}_k
\end{equation}
\begin{figure}
 \begin{tikzpicture}[
    >=latex,
    node distance=2.2cm,
    block/.style={draw, rectangle,fill=blue!15, minimum width=3cm, minimum height=1cm},
    smallblock/.style={draw,fill=blue!15, rectangle, minimum width=2cm, minimum height=1cm},
    sum/.style={draw, circle, fill=blue!15,minimum size=4mm, inner sep=0pt},
    every node/.style={font=\small}
]

% obere Blöcke
\node[block] (f) {$\mathbf{f}(\hat{\mathbf{x}}_{k-1}, \mathbf{u}_{k-1}) $};
\node[block, right=3.5cm of f] (h) {$\mathbf{h}(\hat{\mathbf{x}}_{k|k-1})$};
\node[sum, right=1.5cm of h] (sumR) {};

% K-Block
\node[smallblock, below=1cm of h] (K) {$\mathbf{K}_k$};

% linker Summationspunkt
\node[sum, left=2.2cm of K] (sumL) {};

% Kovarianzblock
\node[block, below=0.5cm of K] (cov) {Kovarianz-Update};

% Hauptpfad oben
\draw[blue,double,double distance=1pt,->] (f) -- node[above] {$\hat{\mathbf{x}}_{k|k-1}$} (h);
\draw[blue,double,double distance=1pt,->] (h) -- node[above]{} (sumR);

% Eingang links in f
\draw[blue,double,double distance=1pt,->] ($(f.west)+(-0.5,0)$) -- ($(f.west)+(0,0)$)
    node[pos=0, left] {$\hat{\mathbf{x}}_{k-1}$};
\draw[blue,double,double distance=1pt,->] ($(f.north)+(-0,0.5)$) -- ($(f.north)+(-0,0)$)
    node[pos=0, above] {$\mathbf{u}_{k-1}$};

% Messvektor z_k
\draw[blue,double,double distance=1pt,->] ($(sumR.north)+(0,0.5)$) -- (sumR.north)
    node[pos=0, above] {$z_k$};

% Vorzeichen am rechten Summationspunkt
\node at ($(sumR.west)+(-0.28,0.22)$) {$-$};

% Innovationspfad
\draw[blue,double,double distance=1pt,->] (sumR.south) |- (K.east);

% Korrekturpfad links
\draw[blue,double,double distance=1pt,->] (K.west) -- (sumL.east);
\draw[blue,double,double distance=1pt,->] (f.east) -|  node[pos=0.95,right] {$+$} (sumL.north);
\draw[blue,double,double distance=1pt,->] (sumL.west) -- ++(-5,0) node[left] {$\hat{\mathbf{x}}_{k}$};

% F_k zum Kovarianz-Update
\draw[red,double,double distance=1pt,->] ($(f.south)+(0,0)$) |- node[pos=0.95,above] {$\mathbf{F}_k$} (cov.west);

% H_k zum Kovarianz-Update
\draw[red,double,double distance=1pt,->] (h.south) -- ++(0,-0.5) -- ++(2.5,0) -- ++(0,-2.5) -- node[pos=0.7,above] {$\mathbf{H}_k$}(cov.east);

% Kovarianz-Update zu K_k
\draw[red,double,double distance=1pt,->] (cov.north) -- (K.south);

% Eingänge unten
\draw[red,double,double distance=1pt,->] ($(cov.south)+(-1.1,-0.5)$) -- ($(cov.south)+(-1.1,0)$)
    node[pos=0, below] {$\mathbf{Q}_{k-1}$};
\draw[red,double,double distance=1pt,->] ($(cov.south)+(0,-0.5)$) -- ($(cov.south)+(0,0)$)
    node[pos=0, below] {$\mathbf{R}_k$};
\draw[red,double,double distance=1pt,->] ($(cov.south)+(1.1,-0.5)$) -- ($(cov.south)+(1.1,0)$)
    node[pos=0, below] {$\mathbf{P}_{k-1}$};
\end{tikzpicture}
\caption{Ablauf eines erweiterten Kalman-Filters}
\label{fig:ekf}

\end{figure}
Der Ablauf des EKF ist quasi identisch zum klassischen Kalman-Filter und in Abbildung \ref{fig:ekf} dargestellt. Wobei die Matrizen Rot und die Vektoren Blau eingefärbt sind, um den Ablauf klarer zu machen. Der Zustandsvektor $\hat{\mathbf{x}}_{k}$ wird im nächsten Schritt als $\hat{\mathbf{x}}_{k-1}$ eingesetzt.
\parencite{RibeiroKalman}\parencite{ExtendedKalmanPhils1}
\subsection{Euler-Verfahren}
\label{subsec:ekf_euler_verfahren}
Das Euler-Verfahren ist ein numerisches Verfahren zur Lösung von gewöhnlichen Differentialgleichungen. Es basiert auf der Idee, die Ableitung einer Funktion an einem bestimmten Punkt zu verwenden, um den Funktionswert an einem nahegelegenen Punkt zu approximieren. 
\begin{equation}
    y_{k+1} = y_k + h \cdot \dot{y}(t)= y_k + h \cdot f(t_k, y_k)
\end{equation}
wobei $y_k$ der Funktionswert zum Zeitpunkt $t_k$, $h$ die Schrittweite und $f(t_k, y_k)$ die Ableitung der Funktion zum Zeitpunkt $t_k$ ist, welcher durch $t_{k} = t_0 + k \cdot h$ definiert ist. $k$ ist eine positive ganze Zahl, welche den Zeitschritt angibt.
\\

\section{Linear Quadratic Gaussian}
\label{sec:lqg_regler}
An diesem Punkt soll die Verbindung zwischen Linear Quadratic Regulator und Kalman-Filter auch Linear Quadratic Estimator genannt vorgestellt werden: Der Linear Quadratic Gaussian (LQG) Regler kombiniert die Vorteile beider Verfahren, indem er die optimale Zustandsrückführung des LQR mit der optimalen Zustandsabschätzung des Kalman-Filters zu einem optimalen Full State Feedback Regler zusammenführt.
\\
Dabei können die beiden optimalen Verfahren unabhängig voneinander ausgelegt werden und anschließend zusammengeführt werden, bleiben jedoch nach wie vor optimal. 
\begin{figure}[H]
\centering
\begin{tikzpicture}[>=latex, thick]
\tikzset{
  block/.style={draw,fill=blue!15, rectangle, minimum width=3cm, minimum height=1.2cm},
  sum/.style={draw,fill=blue!15, circle, minimum size=4mm, inner sep=0pt}
}

% --- Nodes ---
\node[block] (system) at (0,0) {System};
\node[sum]   (sum)    at (4.2,0) {$+$};
\node[block] (lqr)    at (-2.2,-2) {LQR};
\node[block] (lqe)    at ( 2.2,-2) {Kalman-Filter};

% --- Plant input junction (vertical branch for u) ---
\coordinate (ujunc) at (-2.6,0); % junction point left of system

% --- Input u line and into system ---
\draw[-] (-4.2,0) -- node[above] {$\mathbf{u}$} (ujunc);
\draw[->] (ujunc) -- (system.west);

% --- Output y, sum, and output arrow ---
\draw[->] (system.east) -- node[above] {$\mathbf{y}$} (sum.west);
\draw[->] (sum.east) -- ++(1.4,0);

% --- Disturbance and measurement noise ---
\draw[->] (0,1.5) -- node[right] {$\mathbf{w}_d$} (system.north);
\draw[->] (4.2,1.5) -- node[right] {$\mathbf{w}_n$} (sum.north);

% --- Vertical line down from sum (measurement path) ---
% \coordinate (down) at (4.2,-2.4);
% \draw[-] (sum.south) -- (4.2,-2.4);

% --- Into LQE from the right ---
\draw[->] (sum.south)|- (lqe.east);

% --- LQE to LQR with x-hat ---
\draw[->] (lqe.west) -- node[below] {$\hat{\mathbf{x}}$} (lqr.east);

% --- Connection from LQE to the u-branch (missing in previous) ---
% (line leaving LQE top, going to the vertical u-branch)
\draw[<-] (lqe.north) -- ++(0,0.4) -| (ujunc);

% --- LQR to u: must exit LEFT side of LQR and go up to u-branch ---
\draw[-] (lqr.west) -- ++(-0.8,0) |- (ujunc);
\end{tikzpicture}
\caption{LQG Regler Struktur}
\label{fig:lqg_structure}
\end{figure}
In der Abbildung \ref{fig:lqg_structure} ist die Struktur eines LQG-Reglers dargestellt. Das System empfängt die Steuergröße $\mathbf{u}$ und produziert die Ausgangsgröße $\mathbf{y}$. Störgrößen $\mathbf{w}_d$ beeinflussen das System, während Messrauschen $\mathbf{w}_n$ die gemessenen Signale $\mathbf{y}$ stören. Der Kalman-Filter verarbeitet die gemessenen Signale, um eine Schätzung $\hat{\mathbf{x}}$ des Systemzustands zu liefern, welche dann an den LQR weitergegeben wird. Der LQR-Block berechnet die optimale Steuergröße basierend auf der geschätzten Zustandsinformation $\hat{\mathbf{x}}$. 

Das System wird dabei durch folgende bereits bekannte Gleichungen beschrieben:
\begin{equation}
\dot{\mathbf{x}} = \mathbf{A} \cdot \mathbf{x} + \mathbf{B} \cdot \mathbf{u} + \mathbf{w}_d
\end{equation}
\begin{equation}
\mathbf{y} = \mathbf{C} \cdot \mathbf{x} + \mathbf{w}_n
\end{equation}
Der LQG-Regler berechnet die Steuergröße $\mathbf{u}$ auf Basis der geschätzten Zustandsinformation $\hat{\mathbf{x}}$ durch die folgende Rückführung:
\begin{equation}\mathbf{u} = -\mathbf{K}_r \cdot \hat{\mathbf{x}}
\end{equation}
Der Kalman-Filter (hier in seiner kontinuierlichen Form auch Kalman-Bucy Filter genannt) berechnet die Schätzung $\hat{\mathbf{x}}$ des Systemzustands basierend auf den gemessenen Signalen $\mathbf{y}$:
\begin{equation}\hat{\mathbf{x}} = -\mathbf{K}_f \cdot \mathbf{y}\end{equation}
Die Rückführungsmatrix $\mathbf{K}_r$ des LQR und die Kalman-Gain-Matrix $\mathbf{K}_f$ des Kalman-Filters werden unabhängig voneinander berechnet, wobei $\mathbf{K}_r$ auf der Minimierung der Kostenfunktion des LQR basiert und $\mathbf{K}_f$ auf der Minimierung der Kovarianzmatrix des Kalman-Filters basiert.
Wie in den der detaillierten Beschreibungen der beiden Verfahren siehe Kapitel \ref{sec:lqr_regler} und \ref{sec:kalman_filter} beschrieben, sind sich die Berechnungsschritte der Rückführungsmatrix $\mathbf{K}_r$ des LQR und der Kalman-Gain-Matrix $\mathbf{K}_f$ des Kalman-Filters sehr ähnlich, und jeweils auf eine algebraische Riccati-Gleichung zurückzuführen. 
\begin{quote}
Optimal control and estimation are mathematical dual problems, as are controllability and observability.
 \parencite{DataDrivenScience}
\end{quote}
Die vollständige Systemdynamik des LQG-Reglers kann somit durch die folgende Gleichung beschrieben werden:
\begin{equation}
\dot{\hat{\mathbf{x}}} = \mathbf{A} \cdot \hat{\mathbf{x}} + \mathbf{B} \cdot \mathbf{u} + \mathbf{K}_f (\mathbf{y} - \mathbf{C} \cdot \hat{\mathbf{x}})
\end{equation}
\begin{equation}
\mathbf{u} = -\mathbf{K}_r \cdot \hat{\mathbf{x}}
\end{equation}
Wenn die Matrix $\mathbf{K}_f$ in der ersten Gleichung groß ist, vertraut der Schätzer stark auf die Messungen, wenn diese jedoch klein ist, verlässt sich dieser stärker auf die Systemdynamik. Dies hängt davon ab wie stark das Messrauschen $\mathbf{w}_n$ im Vergleich zum Prozessrauschen $\mathbf{w}_d$ ist, und somit wie zuverlässig die Messungen sind.
\parencite{DataDrivenScience}

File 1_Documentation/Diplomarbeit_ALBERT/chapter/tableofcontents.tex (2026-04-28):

%%%%%%%%%%%%%%%%%%%%%%%%%%%%%%%%%%%%%%%%%%%%%%%%%%%%%%%%%%%%%%%%%%%%%%%
%                   Anfang Verzeichnisse
%%%%%%%%%%%%%%%%%%%%%%%%%%%%%%%%%%%%%%%%%%%%%%%%%%%%%%%%%%%%%%%%%%%%%%%

%-------------------------------------------------------------------

% Verzeichnisse

\pagestyle{fancy} % Kopf- und Fußzeilen auch in Verzeichnissen aktivieren

\tableofcontents
\thispagestyle{fancy} 
\listoffigures 
\thispagestyle{fancy} % fancy-Stil für Abbildungsverzeichnis
\addcontentsline{toc}{chapter}{Abbildungsverzeichnis}
\cleardoublepage 
\listoftables
\thispagestyle{fancy} % fancy-Stil für Tabellenverzeichnis
\addcontentsline{toc}{chapter}{Tabellenverzeichnis}

\pagestyle{fancy}
\chapter*{Abkürzungsverzeichnis}
\thispagestyle{fancy}
\pagestyle{fancy}
\addcontentsline{toc}{chapter}{Abkürzungsverzeichnis}
\begin{longtable}{p{3cm}p{10cm}}
ADC           & Analog-Digital-Converter \\
CAD           & Computer-Aided Design \\
CFD           & Computational Fluid Dynamics \\
CG            & Center of Gracity \\
CP            & Center of Pressure \\
DOF           & Degree of Freedom \\
EKF           & Extended Kalman Filter \\
EMV           & Elektromagnetische Verträglichkeit \\
EMI           & Elektromagnetische Interferenz \\
FIFO          & First In, First Out \\
GNSS          & Global Navigation Satellite System \\
GPS           & Global Positioning System \\
I\textsuperscript{2}C           & Inter-Integrated Circuit \\
IC            & Integrated Circuit \\
IDE           & Integrated Development Environment \\
IMU           & Inertial Measurement Unit \\
LDO           & Low-Dropout-Regler \\
LQE           & Linear Quadratic Estimator \\
LQG           & Linear Quadratic Gaussian \\
LQR           & Linear Quadratic Regulator \\
MEMS          & Micro-Electro-Mechanical System \\
MPU           & Main Processing Unit \\
NACA          & National Advisory Committee for Aeronautics \\
NAV           & Navigation Processing Unit \\
PCB           & Printed Circuit Board \\
PID           & Proportional-Integral-Differential \\
PLA           & Polylactic Acid \\
PWM           & Pulsweitenmodulation \\
SPI           & Serial Peripheral Interface \\
UART          & Universal Asynchronous Receiver Transmitter \\
USB           & Universal Serial Bus \\
\end{longtable}
\newpage
\chapter*{Projektteam}
\thispagestyle{fancy}
\pagestyle{fancy}
\addcontentsline{toc}{chapter}{Projektteam}
\begin{figure}[H]
    \centering
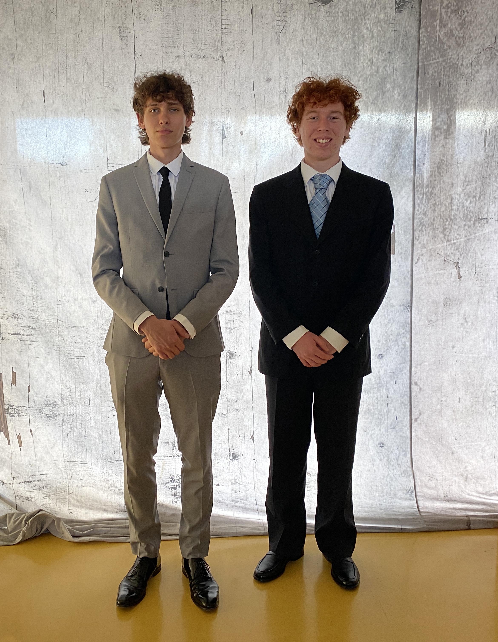
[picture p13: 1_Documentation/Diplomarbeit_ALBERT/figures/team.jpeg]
    
    \caption{Projektteam ALBERT (v.l.n.r.): Timofey Luzin, Felix Zauner}
    \label{fig:projektteam}
\end{figure}

\section*{Aufgabenverteilung}
\subsection*{Felix Zauner}
\textbf{Projektbetreuer:}  Dipl.-Ing., Dipl.-Ing.(FH) Johannes Ferner\\
\textbf{Aufgaben:}
\begin{itemize}
    \item Entwicklung des Flightcomputers (Hardware \& Software)
    \item Entwicklung der Regelung 
\end{itemize}

\subsection*{Timofey Luzin}
\textbf{Projektbetreuer:} Dipl.-Ing. Franz Reich \\
\textbf{Aufgaben:}
\begin{itemize}
    \item Entwicklung des gesamten mechanischen Aufbaus
    \item Simulation der Aerodynamik
\end{itemize}

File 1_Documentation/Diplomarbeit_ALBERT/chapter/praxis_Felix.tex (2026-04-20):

\chapter{Flightcomputer \textit{KOMADORI}}
\label{ch:komadori}
\fancyfoot[C]{\large Felix Zauner}
\fancypagestyle{plain}{\fancyfoot[C]{\large Felix Zauner}}

\section{Anforderungsanalyse}
\label{sec:anforderungsanalyse}
In der Planungsphase des Flightcomputers ist es entscheidend, die Anforderungen an das System klar zu definieren, um sicherzustellen, dass der entwickelte Flightcomputer alle zukünftigen Anforderungen erfüllt. 
\\
Die Anforderungen wurden in aktive und passive Anforderungen unterteilt. Aktive Anforderungen beziehen sich auf die Funktionen, die der Flightcomputer erfüllen muss, wie z.B. die Fähigkeit, Sensordaten zu erfassen, Regelalgorithmen schnell genug auszuführen und die Kommunikation mit anderen Systemen zu ermöglichen. Passive Anforderungen beziehen sich auf die Eigenschaften des Flightcomputers und dessen Komponenten, wie z.B. Formfaktor und Zuverlässigkeit in stark beschleunigten und vibrierdenden Umgebungen.
\\

\textbf{Aktive Anforderungen:}
\begin{itemize}
    \item Erfassung folgender Sensordaten zur Bestimmung von Fluglage, Geschwindigkeit, Höhe sowie Position:
    \begin{itemize}
        \item Beschleunigung mittels 3-Achsen-Beschleunigungssensor
        \item Winkelgeschwindigkeit mittels 3-Achsen-Gyroskop
        \item Magnetfeldmessung zur Ausrichtungsbestimmung mittels 3-Achsen-Magnetometer
        \item Luftdruckmessung zur Höhenbestimmung mittels Barometer
        \item Positionsbestimmung mittels GNSS-Modul
    \end{itemize}
    \item Bereitstellung von PWM-Ausgängen zur Ansteuerung der Servoantriebe der Finnensteuerung.
    \item Bereitstellung von Pyro-Kanälen zur Zündung des Fallschirmauswurfmechanismus.
    \item Telemetrieübertragung über LoRa zur Datenkommunikation mit der Bodenstation während des Fluges.
    \item Speicherung der Flugdaten auf einem SD-Kartenmodul zur nachträglichen Analyse.
    \item Bereitstellung von Kommunikationsschnittstellen (SPI, I\textsuperscript{2}C und UART) zur Integration externer Sensoren und Aktuatoren.
    \item Versorgung über einen 2S-LiPo-Akku mit einem Spannungsbereich von 7,4\,V bis 8,4\,V.
    \item Möglichkeit zur Programmierung sowie zum Datenlogging über eine USB-C-Schnittstelle.
    \item Unterstützung von Debugging und Fehlersuche über eine SWD-Schnittstelle (Serial Wire Debug) mittels ST-Link.
    \item Einhaltung einer maximalen Latenzzeit von unter 10\,ms zwischen Messwerterfassung und Steuerungsaktion, um eine ausreichend schnelle Reaktion auf Flugbedingungen sicherzustellen.
\end{itemize}

\vspace{20pt}

\textbf{Passive Anforderungen:}
\begin{itemize}
    \item Kompakter Formfaktor mit maximalen Abmessungen von 110\,mm $\times$ 78\,mm zur Integration in die Rakete.
    \item Auswahl geeigneter Sensoren für Beschleunigungen von bis zu 15\,g, um den mechanischen Belastungen während des Betriebs standzuhalten und valide Messwerte zu gewährleisten.
    \item Verwendung vibrationssicherer und zuverlässiger Steckverbinder zur Gewährleistung stabiler Verbindungen zu externen Sensoren, Aktuatoren sowie der Stromversorgung.
    \item Implementierung von ESD-Schutzmaßnahmen zum Schutz vor elektrostatischer Entladung.
    \item Ausführung der USB-C-Schnittstelle mit geeigneten Schutzmaßnahmen zum Schutz angeschlossener Endgeräte vor elektrischen Fehlzuständen, Überspannungen und Fehlströmen.
\end{itemize}

\section{Systemarchitektur}
\label{sec:systemarchitektur}
Ausgehend von den Anforderungen an die Funktionen und Eigenschaften des Flight Computers wird im Folgenden die Systemarchitektur (siehe Abbildung \ref{fig:systemarchitektur}) erarbeitet, um das Zusammenspiel der verschiedenen Komponenten hinsichtlich ihrer Funktionen zu strukturieren und damit eine Grundlage für die weiteren Entwicklungsschritte zu schaffen. 
\begin{figure}[H]
    \centering
    
    \begin{tikzpicture}[
    font=\sffamily,
    node distance=7mm and 10mm,
    box/.style={draw, rounded corners=2pt, minimum width=20mm, minimum height=10mm, align=center},
    bigbox/.style={draw, rounded corners=2pt, minimum width=50mm, minimum height=18mm, align=center},
    arr/.style={-latex, line width=0.8pt}
    ]

    % --- Nodes (top row sensors) ---
    \node[box, fill=violet!20] (imu1) {IMU 1};
    \node[box, fill=violet!20, right=of imu1] (baro) {Barometer};
    \node[box, fill=violet!20, right=of baro] (mag) {Magnetometer};

    % --- Center navigation computer ---
    \node[box, fill=red!20, minimum width=45mm, minimum height=14mm,
        below=10mm of baro] (nav) {Navigation Computer};

    % --- Side sensors ---
    \node[box, fill=violet!20, left=10mm of nav] (imu2) {IMU 2};
    \node[box, fill=violet!20, right=10mm of nav] (gps) {GPS};

    % --- Main processing unit ---
    \node[bigbox, fill=green!20, below=12mm of nav] (mpu) {Main Processing Unit};

    % --- Peripherals around MPU ---
    \node[box, fill=orange!25, left=10mm of mpu] (lora) {LoRa};

    \node[box, fill=red!30, right=10mm of mpu, yshift=8mm] (sd) {SD-Karte};
    \node[box, fill=red!30, right=10mm of mpu, yshift=-8mm] (flash) {Flash};

    \node[box, fill=yellow!30, below left=10mm and -20mm of mpu] (servos) {Servos};
    \node[box, fill=yellow!30, below right=10mm and -20mm of mpu] (pyro) {Pyro Kan\"ale};

    % --- Arrows: sensors -> nav ---
    \draw[arr] (imu1.south) -- (nav.north west);
    \draw[arr] (baro.south) -- (nav.north);
    \draw[arr] (mag.south) -- (nav.north east);
    \draw[arr] (imu2.east) -- (nav.west);
    \draw[arr] (gps.west) -- (nav.east);

    % --- Arrows: nav -> mpu ---
    \draw[arr] (nav.south) -- (mpu.north);

    % --- Arrows: mpu -> peripherals ---
    \draw[arr] (mpu.west) -- (lora.east);
    \draw[arr] (mpu.east) -- (sd.west);
    \draw[arr] (mpu.east) -- (flash.west);
    \draw[arr] (mpu.south) -- (servos.north);
    \draw[arr] (mpu.south) -- (pyro.north);

    \end{tikzpicture}
    
    \caption{Systemarchitektur des Flightcomputers}
    \label{fig:systemarchitektur}
\end{figure}
Die Hardwarearchitektur des Flightcomputers gliedert sich in zwei Hauptkomponenten: Navigation Processing Unit (NAV) mit den Sensoren und Main Processing Unit (MPU) mit der Aktuatorik, den Datenspeichern sowie der Telemetrie (LoRa). Die NAV ist für die Erfassung der Sensordaten und die Berechnung von Fluglage, Geschwindigkeit und Position verantwortlich. Er empfängt die Daten der Sensoren (IMU 1, IMU 2, Barometer, Magnetometer und GPS) und verarbeitet diese mittels Sensor Fusion (siehe Kapitel \ref{subsec:erweiterter_kalman_filter}).
\\
Wohingegen die MPU die zentrale Steuereinheit des Flightcomputers darstellt, welche die Steuerungsalgorithmen ausführt, die Aktuatoren (Servos und Pyro-Kanäle) ansteuert, die Flugdaten auf der SD-Karte und im Flash-Speicher speichert sowie die Telemetriedaten über LoRa überträgt. Die MPU empfängt die Zustandsschätzung vom NAV und verarbeitet diese mittels LQR Regelung (siehe Kapitel \ref{sec:lqr_regler}), um die erforderlichen Steuerbefehle für die Servos zu berechnen.
\\
Die Trennung der Aufgabenbereiche dient primär der Echtzeitsicherheit und der funktionalen Entkopplung. Der NAV verarbeitet hochfrequente Sensordaten (insbesondere IMU) und schätzt den aktuellen Zustand auf Basis der Sensordaten mittels Extended Kalman Filter. Diese Berechnungen erfordern konstante Latenzzeiten und dürfen nicht durch blockierende Operationen wie Speicherzugriffe oder Funkkommunikation beeinflusst werden. Durch die Auslagerung von potenziell nichtdeterministischen Aufgaben auf eine separate MPU wird sichergestellt, dass die Zustandsschätzung auch bei hoher Systemlast stabil bleibt. Darüber hinaus reduziert die funktionale Trennung die Softwarekomplexität.
\\ 
Zur sicheren Speicherung der Flugdaten werden diese während des Fluges im Flash-Speicher abgelegt und erst nach der Landung auf die SD-Karte übertragen. Dies verhindert Datenverluste, da bei starken Vibrationen eine Datenübertragung über die Kontakte der SD-Karte nicht gewährleistet werden kann.
\section{Komponentenauswahl}
\label{sec:komponentenauswahl}
Im Folgenden wird die Auswahl der wichtigsten Komponenten des Flightcomputers erläutert und begründet. Für die spätere Treiberentwicklung ist bereits bei der Auswahl der Komponenten darauf zu achten, dass umfangreiche Dokumentationen und im Idealfall Referenztreiber vorhanden sind, da dies den späteren Zeitaufwand erheblich reduziert. Des Weiteren ist unbedingt darauf zu achten, dass die ausgewählten Komponenten beim ausgewählten Leiterplattenhersteller verfügbar sind.

\subsection{Sensoren}
\label{subsec:sensoren}
\subsubsection{\href{https://www.bosch-sensortec.com/products/motion-sensors/imus/bmi088/}{IMU1 - BMI088}}
Das BMI088 ist speziell für hochdynamische Anwendungen mit starken Vibrationen konzipiert und eignet sich daher ideal für den Einsatz in Raketen. Es beinhaltet einen 3-Achsen-MEMS-Beschleunigungssensor mit einem Messbereich von bis zu $\pm$ 24\,g und einen 3-Achsen-Gyroskop mit einem Messbereich von bis zu $\pm$ 2000\,°/s. Diese Spezifikationen decken den Arbeitsbereich des Flightcomputers mit ausreichend Sicherheitsreserven ab und verhinderen bei starken Beschleunigungen am Start das Abschneiden von Signalen außerhalb des Messbereichs.

\subsubsection{\href{https://www.st.com/en/mems-and-sensors/lsm6dsl.html}{IMU2 - LSM6DSLTR}}
Aufgrund der immensen Wichtigkeit der IMU-Daten für die Lagebestimmung des Systems, wird eine Inertial Measurement Unit als Backup verwendet. Der LSM6DSLTR bietet mit einem Messbereich von bis zu $\pm$ 16\,g für den Beschleunigungssensor und $\pm$ 2000\,°/s für das Gyroskop ausreichend Reserven und kann in den Sensor Fusion Algorithmus integriert werden, um die Robustheit der Zustandsschätzung zu erhöhen.
\subsubsection{\href{https://www.bosch-sensortec.com/products/environmental-sensors/pressure-sensors/bmp390/}{Barometer - BMP390}}
Der Drucksensor wird für die Höhenbestimmung verwendet. Mit einem Arbeitsbereich von 300-1250\,hPa und einer Genauigkeit von 0.50\,hPa erfüllt der BMP390 die Anforderungen problemlos und kann als zusätzlicher Stützwert für die Zustandsschätzung sowie als verlässliche Entscheidungsgrundlage für den Fallschirmauswurf dienen.
\subsubsection{\href{https://www.bosch-sensortec.com/media/boschsensortec/downloads/datasheets/bst-bmm150-ds001.pdf}{Magnetometer - BMM150}}
Das Magnetometer wird verwendet, um die Ausrichtung der Rakete in Bezug auf den Referenzrahmen der Erde zu bestimmen. Dabei ist zu beachten, dass die Messungen durch magnetische Störfelder auf der Platine beeinflusst und somit verfälscht werden können. Das BMM150 hat einen Messbereich von $\pm$ 1300\,$\mu$T und eine Auflösung von 0.3\,$\mu$T.
\subsection{Prozessoren}
\label{subsec:prozessoren}
Für die Auswahl der beiden Prozessoren des Flightcomputers – der Navigation Processing Unit (NAV) sowie der Main Processing Unit (MPU) – wurde besonderer Wert auf eine umfassende technische Dokumentation, die zuverlässige Verfügbarkeit über den Leiterplattenhersteller JLCPCB sowie eine breite communitybasierte Nutzung gelegt.
\\
Zum Zeitpunkt des Projektbeginns beschränkte sich die schulische Ausbildung im Bereich der Mikrocontroller-Programmierung ausschließlich auf den Einsatz der Arduino-Plattform. Eine vertiefte Auseinandersetzung mit hardwarenaher Embedded-Programmierung, eigenständigem Leiterplattendesign oder der Entwicklung komplexerer Systeme war im bisherigen Unterricht nicht vorgesehen und musste sich in Eigeninitiative angeeignet werden.
\\
Aus den oben genannten Gründen wird für die Navigation Processing Unit (NAV) der STM32F405RGT6 von STMicroelectronics ausgewählt, da dieser Mikrocontroller eine leistungsfähige Arm Cortex-M4 CPU mit einer Taktfrequenz von bis zu 168\,MHz bietet, was ausreichend Rechenleistung für die Echtzeitverarbeitung der Zustandsschätzung gewährleistet sowie genügend Schnittstellen zur Anbindung von Sensoren bereitstellt
\\
Für die Main Processing Unit (MPU) wird der STM32H753VIT6 ausgewählt, da dieser mit einer ARM Cortex-M7 CPU mit einer Taktfrequenz von bis zu 400\,MHz eine deutlich höhere Rechenleistung bietet, die für die Regelung, das Peripheriemanagement und die Telemetrieübertragung in Echtzeit mehr als ausreichend ist und zudem zusätzliche Pins für externe Peripherie bietet. 
\\
Der zentrale Vorteil der STM32-Plattform liegt in der stark ausgeprägten Community-Unterstützung. Neben der offiziellen Dokumentation stehen zahlreiche technisch hochwertige, communitygetriebene Lernressourcen zur Verfügung, welche die eigenständige Einarbeitung in komplexere Themenbereiche um ein vielfaches erleichtern.

\subsection{Weitere Peripheriekomponenten}
\label{subsec:weitere_peripheriekomponenten}
\subsubsection{Servos - BMS-125WV+}
Für die Ansteuerung der Finnen sind Servos notwendig, welche die erforderlichen Kräfte und Geschwindigkeiten bereitstellen können, zugleich aber auch kompakt genug sind um in den Rumpf zu passen. Die BMS-125WV+ Servos bieten mit einem Stellmoment von 7,1\,kg/cm sowie einer Geschwindigkeit von 0.09\,s/60° bei 8.4\,V ausreichend Leistung für die Finnensteuerung und sind mit Abmessungen von 23.2\,mm $\times$ 10\,mm $\times$ 23\,mm ideal für die Integration in die Rakete. Die Servos werden per Pulsweitenmodulation (PWM) über den PWM-Controller angesteuert.
\subsubsection{\href{https://www.nxp.com/products/power-drivers/lighting-driver-and-controller-ics/led-drivers/16-channel-12-bit-pwm-fm-plus-ic-bus-led-driver:PCA9685}{PWM-Controller - PCA9685PW,118}}
Um acht Servos anzusteuern, ist die Implementierung eines PWM-Controllers sinnvoll, da sich so die Anzahl der belegten Pins der MPU reduziert und die Ansteuerung der Servos vereinfacht wird.
Die Steuerbefehle werden dabei per I\textsuperscript{2}C-Schnittstelle von der MPU übermittelt. Der PCA9685PW,118 bietet 16 Kanäle mit 12-Bit-Auflösung und ist mit einem Betriebsspannungsbereich von 2.3\,V bis 5.5\,V kompatibel mit der Logikspannung der MPU.
\subsubsection{\href{https://www.infineon.com/assets/row/public/documents/24/49/infineon-bsc028n06ls3-g-datasheet-en.pdf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}{Pyro-Kanäle-Mosfets - BSC028N06LS3}}
Um den Fallschirm auszuwerfen, werden Pyro-Kanäle benötigt, welche die pyrotechnischen Ladungen zünden. Die BSC028N06LS3 N-Kanal-MOSFETs bieten mit einem maximalen Drain-Strom von 28\,A und einer maximalen Drain-Source-Spannung von 60\,V mehr als genug Leistung für die Zündung und können direkt über Logic Level sprich die MPU angesteuert werden.

\subsubsection{\href{https://www.ti.com/product/TPS54308}{Buck Converter - TPS54308}}
Um die Komponenten des Flightcomputers mit der benötigten Spannung von 3.3\,V zu versorgen, wird ein Buck Converter benötigt, welcher die Eingangsspannung von 7.4-8.4\,V des 2S-LiPo-Akkus auf die benötigte Spannung herunterregelt. Der TPS54308 bietet mit einem Eingangsspannungsbereich von 5.5\,V bis 36\,V und einem Ausgangsstrom von bis zu 3\,A ausreichend Leistung für die Versorgung aller Komponenten des Flightcomputers. 
\\
\\
Auf die Auswahl der Komponenten für die SD-Karte, den Flash-Speicher, des LoRa-Moduls, des GPS-Moduls sowie des PWM-Controllers wird an dieser Stelle nicht weiter eingegangen, da diese auf Basis der Verfügbarkeit bei JLCPCB, den bereits beschriebenen Anforderungen sowie der vorhandenen Dokumentation ausgewählt wurden und eine detaillierte Erläuterung dem Kapitel keinerlei Mehrwert bieten würde.
 
\section{Schaltungsentwurf}
\label{sec:schaltungsentwurf}
Im folgenden wird der Entwicklungsprozess und der Aufbau der Schaltung näher erläutert. Dabei wird auf die Versorgungskonzept, die Sensorik sowie die Prozessoren genauer eingegangen. Für die vollständigen Schaltpläne wird auf den Anhang verwiesen (siehe Anhang \ref{ch:komadori_schaltplan}), da diese aufgrund der Komplexität und des Umfangs an dieser Stelle nicht sinnvoll dargestellt werden können.

\subsection{Sensoren}
\label{subsec:sensoren}
Den wichtigsten Teil der Sensorik stellt die IMU1 (BMI088) dar, welche die Hauptquelle für die Daten der Zustandsschätzung ist. Für eine möglichst hohe Datenrate und damit eine möglichst genaue Zustandsschätzung wird die IMU1 über die SPI-Schnittstelle an die Navigation Processing Unit angebunden, da diese im Vergleich zu I\textsuperscript{2}C eine höhere Datenrate ermöglicht. Die IMU2 (LSM6DSLTR) sowie das Magnetometer (BMM150) werden über die I\textsuperscript{2}C-Schnittstelle angebunden.
Im folgenden soll genauer auf die Anbindung der IMU1 eingegangen werden, da diese repräsentativ für alle Sensoren ist.
\\
Die beiden Sensoren der IMU1 (Beschleunigungssensor und Gyroskop) teilen sich das gleiche SPI-Interface (CLK, MOSI, MISO), sind aber als zwei separate Sensoren implementiert und müssen daher mit separaten CS-Leitungen versehen werden. Für eine ressourcenschonende Anbindung werden zwei Data Ready Interrupts (DRDY) verwendet, die der NAV-Unit mitteilen, dass neue Daten des jeweiligen Sensors zum Auslesen bereitstehen. Um den Sensor im SPI-Modus zu betreiben, muss der PS-Pin auf GND gezogen werden. Auf den Versorgungsleitungen befinden sich zusätzlich 100\,nF Keramikkondensatoren als Entkoppelkondensatoren (siehe Abbildung \ref{fig:IMU1Schematic}). Die in der Abbildung gezeigten Widerstände dienen der Zustandsdefinition beim Einschalten, sind aber in keiner Weise kritisch und können weggelassen werden.

\begin{figure}[H]
  \centering
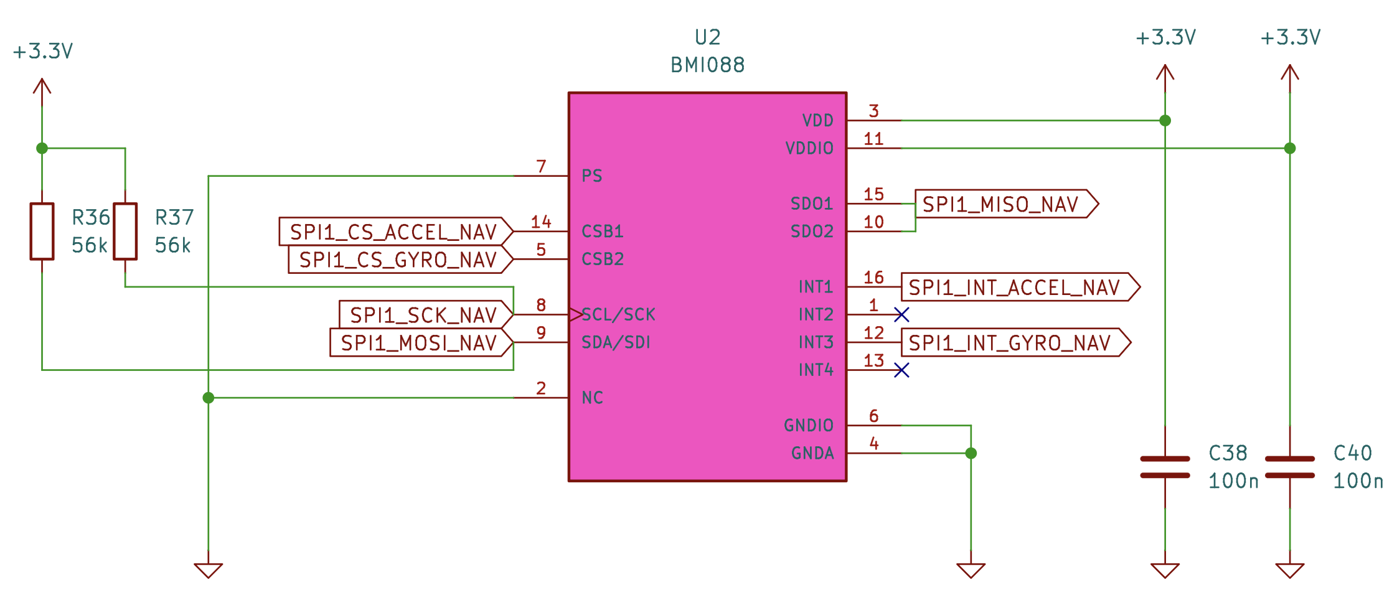
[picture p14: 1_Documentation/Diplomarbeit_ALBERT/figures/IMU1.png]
    
    
    \caption{Schaltplan des BMI088 }
    \label{fig:IMU1Schematic}
\end{figure}

\subsection{Prozessoren}
\label{subsec:prozessoren}
Die Anbindung der beiden Prozessoren erfordert eine Reihe von passiven Bauelementen, um einen stabilen Betrieb zu gewährleisten. Im Folgenden wird auf die Anbindung der MPU (STM32H753VIT6) näher eingegangen, da die Anbindung der NAV (STM32F405RGT6) grundsätzlich identisch ist. \cite{STM32F405xI} \cite{STM32H753xI} 
\\
Der wichtigste Punkt in Bezug auf die Anbindung des Prozessors ist eine stabile Spannungsversorgung von 3.3\,V der verschiedenen Spannungsschienen. Diese teilen sich wie folgt auf: 
\begin{itemize}
    \item VDD: Versorgungsspannung der internen Logik und In- und Outputs des Prozessors
    \item VDDA: Versorgungsspannung der analogen Komponenten des Prozessors (ADC, DAC, etc.)
    \item VREF+ : Interne Referenzspannung
    \item VBAT: Versorgungsspannung über externe Batterie
\end{itemize}
VDD ist direkt mit der 3,3\,V-Schiene verbunden, wobei zwischen jedem der fünf VDD-Pins und Masse ein 100\,nF Keramikkondensator als Entkoppelkondensator eingesetzt wird, um die Stabilität der Versorgung zu gewährleisten, zusätzlich zu den 100\,nF Keramikkondensatoren wird ein 10\,\si{\micro\farad} Kondensator eingesetzt, um größere Ströme zu kompensieren. 
Um die durch die digitalen Schaltvorgänge auf der 3,3\,V-Schiene verursachten hochfrequenten Störungen zu minimieren, werden die Pins VDDA und VREF+ von der VDD-Schiene durch ein PI-Filter entkoppelt, der aus zwei 1\,\si{\micro\farad}-Kondensatoren, einem 10\,nF Keramikkondensator und einer Ferritperle (Induktivität) mit einer Impedanz von 100\,\si{\ohm} besteht (siehe Abbildung \ref{fig:pifilter}). Für VREF+ wird zusätzlich ein RC-Tiefpass eingefügt, um eine möglichst konstante Referenzspannung zu gewährleisten. Der Widerstand stellt hier kein Problem dar, da kein nennenswerter Strom fließt. Da keine externe Batterie verwendet wird, kann der VBAT-Pin wie ein VDD-Pin behandelt werden.
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

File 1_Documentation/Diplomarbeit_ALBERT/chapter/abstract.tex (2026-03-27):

%%%%%%%%%%%%%%%%%%%%%%%%%%%%%%%%%%%%%%%%%%%%%%%%%%%%%%%%%%%%%%%%%%%%%%%
%                   ANFANG ABSTRACT
%%%%%%%%%%%%%%%%%%%%%%%%%%%%%%%%%%%%%%%%%%%%%%%%%%%%%%%%%%%%%%%%%%%%%%%
%
% Autor: Felix Zauner, Franz Spatzenegger
%
%
% WICHTIG:
%   Bitte füllen Sie die imfolgenden mit "AUSFÜLLEN" gekennzeichneten Felder gewissenhaft aus.
%   Felder mit "NICHT AUSFÜLLEN" sind vom Benutzer nicht zu bearbeiten da schon vorausgefüllt.
%
% Der in den Feldern stehende Text dient nur als Beispiel und muss entsprechend angepasst werden.
%
%
% Erneuter Hinweis bezüglich Einbindung der benötigten Pakete für Abstract
%
%   Benötigte Pakete für Abstract
%       \usepackage{graphicx}       % für Grafiken
%       \usepackage[T1]{fontenc}    % für Umlaute und Sonderzeichen
%
% 
% Bei Problemen jeglicher Art wenden Sie sich bitte an einen der Autoren dieser Vorlage.
%
%
%%%%%%%%%%%%%%%%%%%%%%%%%%%%%%%%%%%%%%%%%%%%%%%%%%%%%%%%%%%%%%%%%%%%%%%   

\begin{center}
    {\fontsize{30}{36}\selectfont\bfseries Diplomarbeit}\\[0.5em]
    {\fontsize{20.74}{24}\selectfont\bfseries Dokumentation}
\end{center}
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

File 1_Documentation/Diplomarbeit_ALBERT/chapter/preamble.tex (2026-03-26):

\usepackage[a4paper,top=2cm,bottom=2cm,left=3cm,right=3cm,marginparwidth=1.75cm]{geometry}
\usepackage[utf8]{inputenc}
\usepackage[ngerman]{babel}
\usepackage{graphicx}
\usepackage{geometry}
\usepackage[T1]{fontenc}    % für Umlaute und Sonderzeichen
\usepackage[charter]{mathdesign}     % Palatino - professionelle Serifenschrift für Diplomarbeiten
\usepackage{setspace}
\usepackage{caption}
\usepackage{tabularx}
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

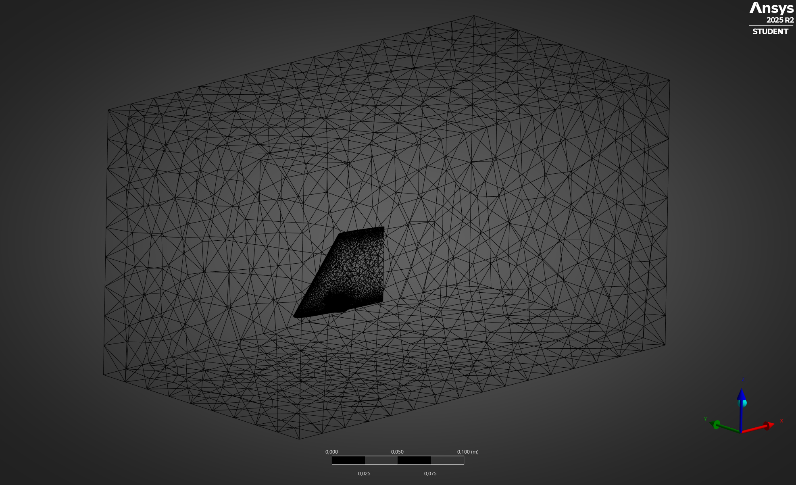
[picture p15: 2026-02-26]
1_Documentation/Diplomarbeit_ALBERT/figures/ansys_mechanical.png

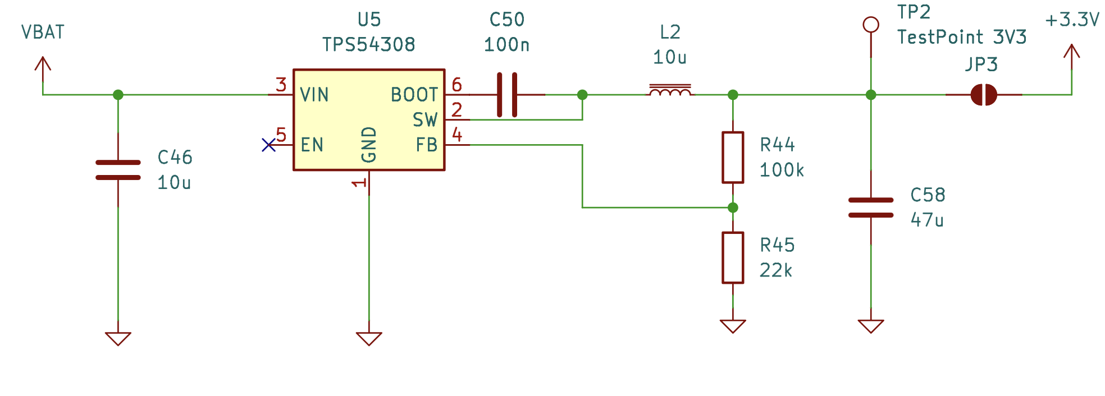
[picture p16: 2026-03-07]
1_Documentation/Diplomarbeit_ALBERT/figures/BuckSchematic.png

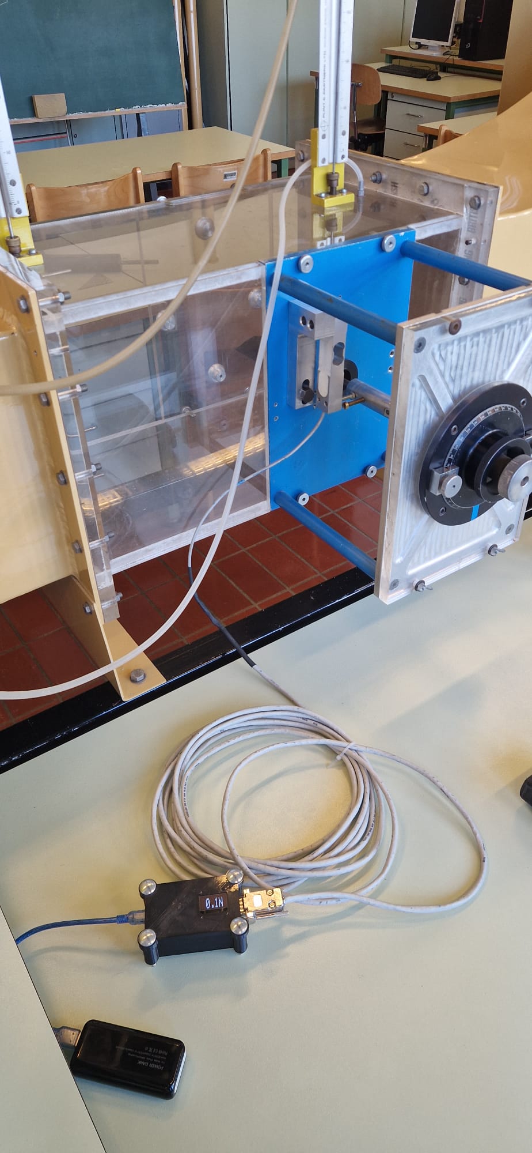
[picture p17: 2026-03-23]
1_Documentation/Diplomarbeit_ALBERT/figures/dehnmessstreifen_newtonmeter.jpg

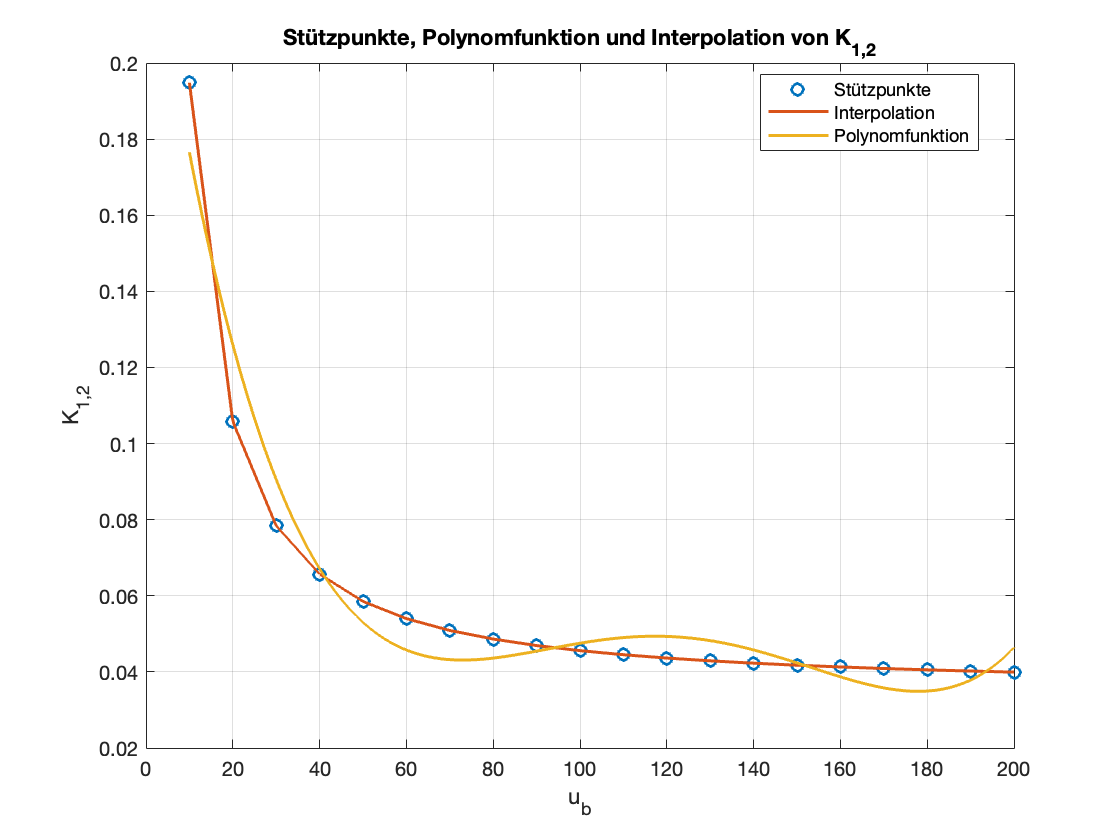
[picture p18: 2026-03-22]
1_Documentation/Diplomarbeit_ALBERT/figures/k_fitting.png

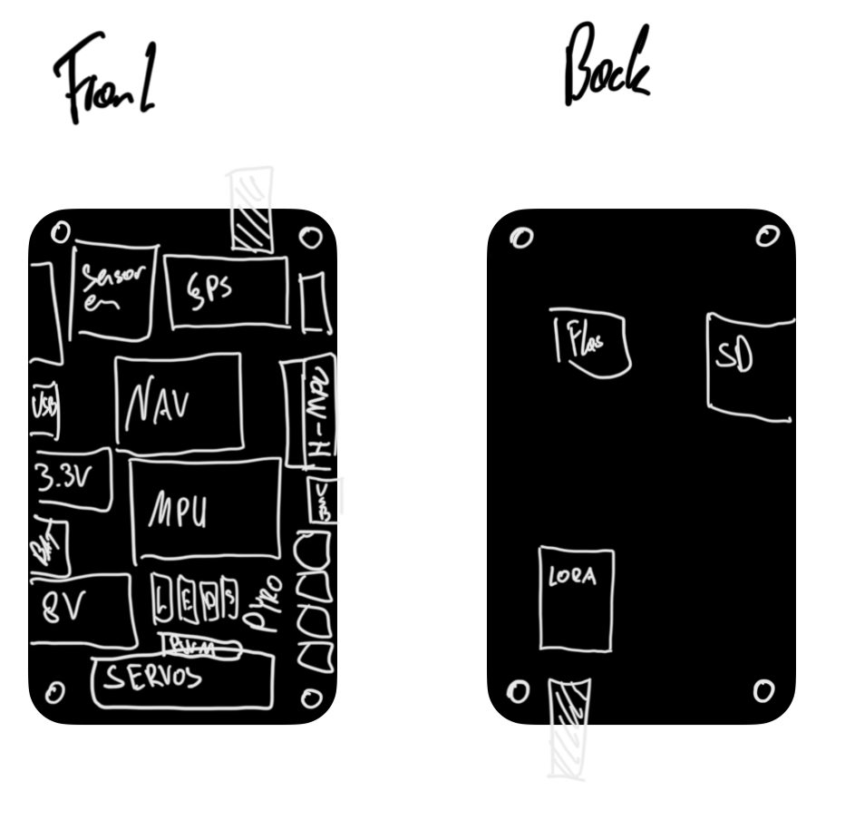
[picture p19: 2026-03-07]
1_Documentation/Diplomarbeit_ALBERT/figures/sketch.png

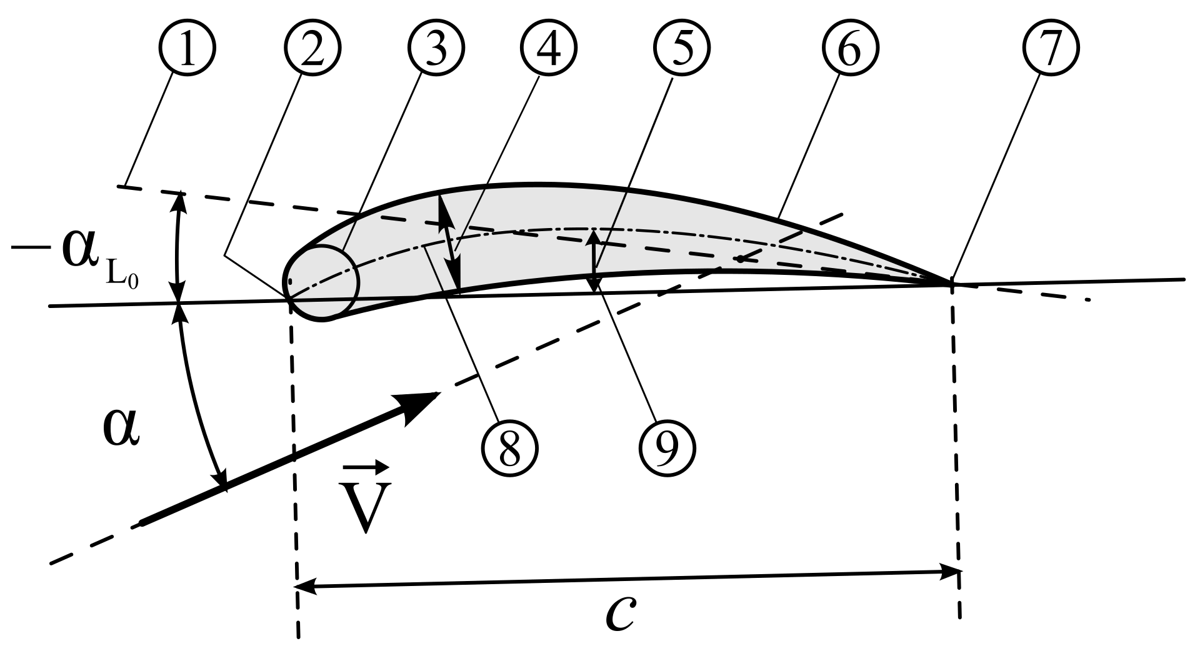
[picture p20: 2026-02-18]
1_Documentation/Diplomarbeit_ALBERT/figures/naca_geometry.png

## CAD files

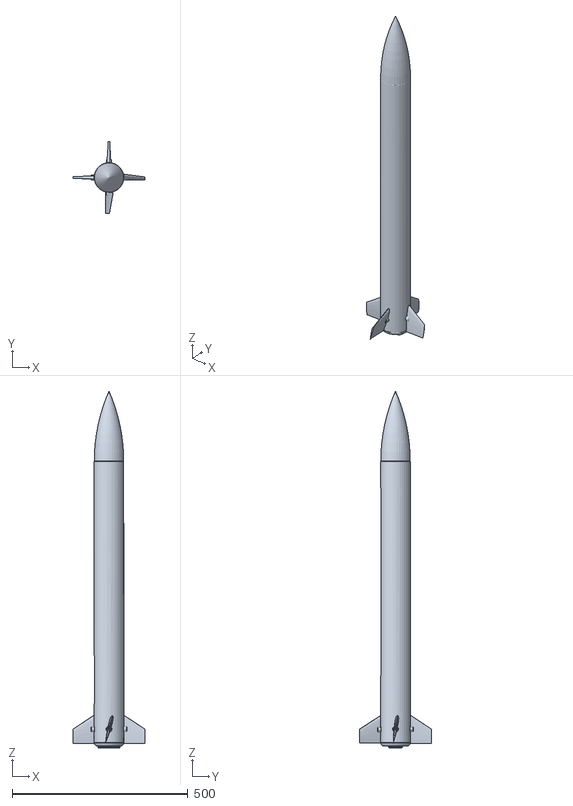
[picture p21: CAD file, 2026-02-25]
2_CAD_Structure/animation/ALBERT_assembly.obj
205.3 x 205.3 x 1015.0

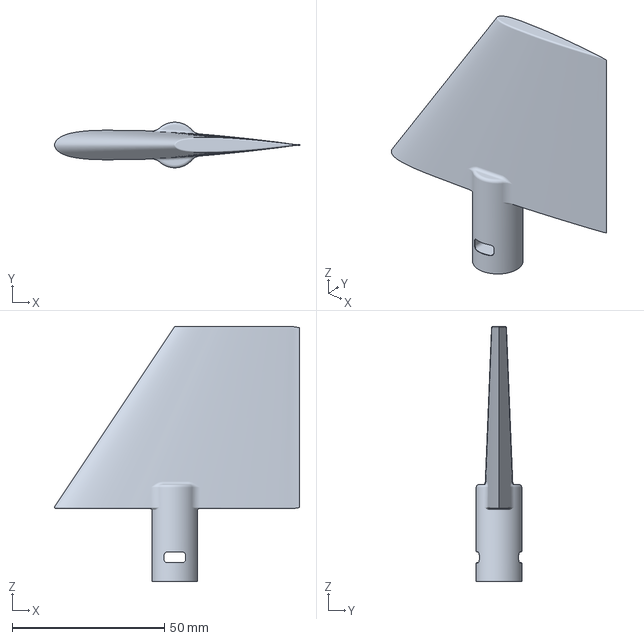
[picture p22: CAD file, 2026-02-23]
2_CAD_Structure/3d_druck/4maldrucken/NACA0012.3mf
80.6 x 15.0 x 84.0 mm

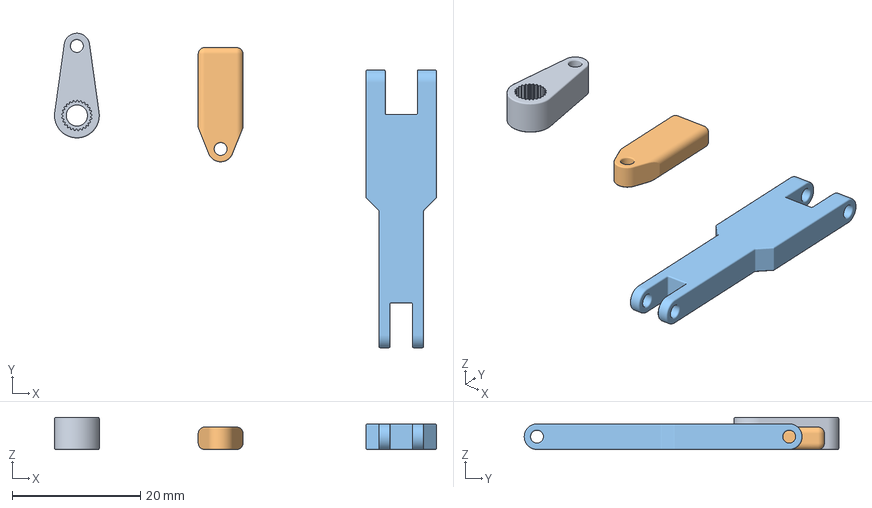
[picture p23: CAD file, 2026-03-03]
2_CAD_Structure/3d_druck/kleine_teile_einzeln/Drehmomentaufnahme_Servo_Fixed.3mf
59.7 x 49.1 x 5.00 mm
Drehmomentaufnahme_Servo_Fixed
Drehmomentaufnahme_Finne_Fixed
Drehmomentaufnahme_Verbindung_Fixed

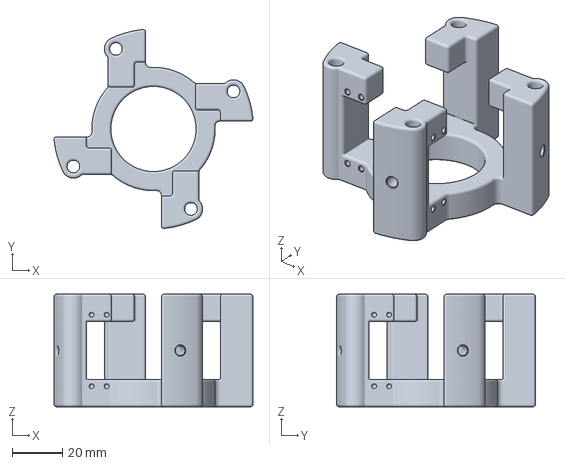
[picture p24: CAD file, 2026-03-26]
2_CAD_Structure/3d_druck/Servomotor_Halterung.3mf
79.6 x 79.6 x 45.0 mm

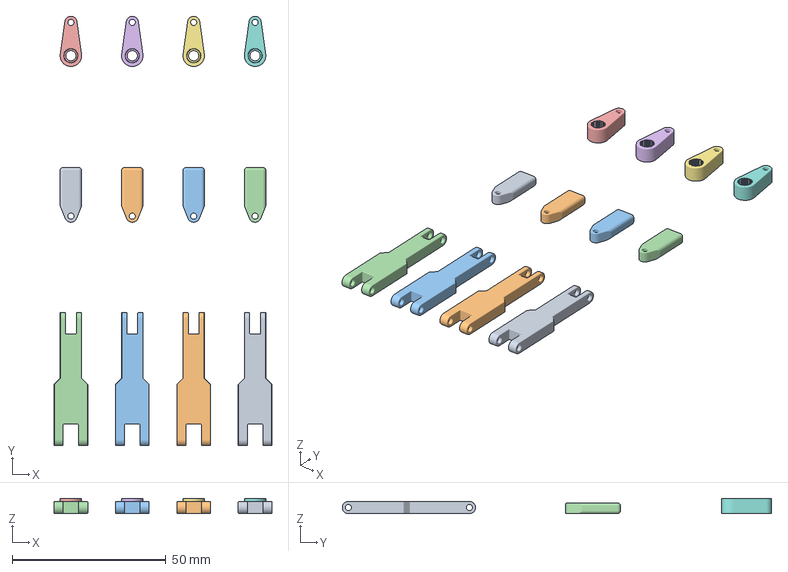
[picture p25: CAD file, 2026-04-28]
2_CAD_Structure/3d_druck_rest/3mf/Drehmomentaufnahme_Finne_Fixed.3mf
71.0 x 139.9 x 5.00 mm
Drehmomentaufnahme_Finne_Fixed x 4
Drehmomentaufnahme_Servo_Fixed x 4
Drehmomentaufnahme_Verbindung_Fixed x 4

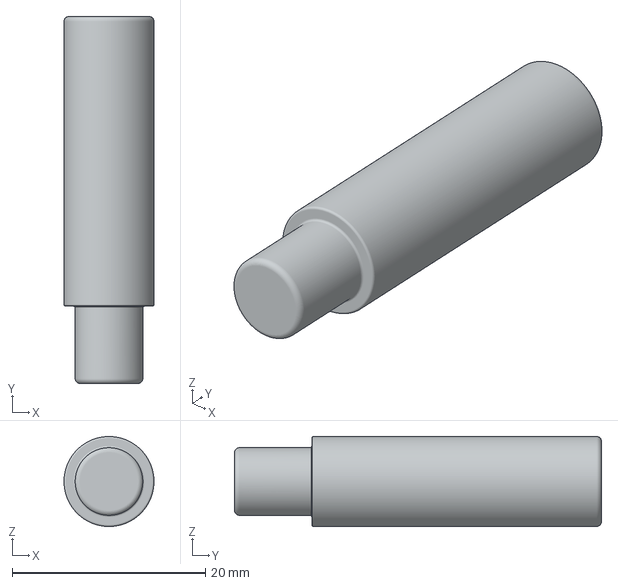
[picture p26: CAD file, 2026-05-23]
2_CAD_Structure/3d_druck_rest/Flightcomputer_halterung_aufgeteilt/carbonstab_halterung.3mf
9.32 x 38.0 x 9.32 mm

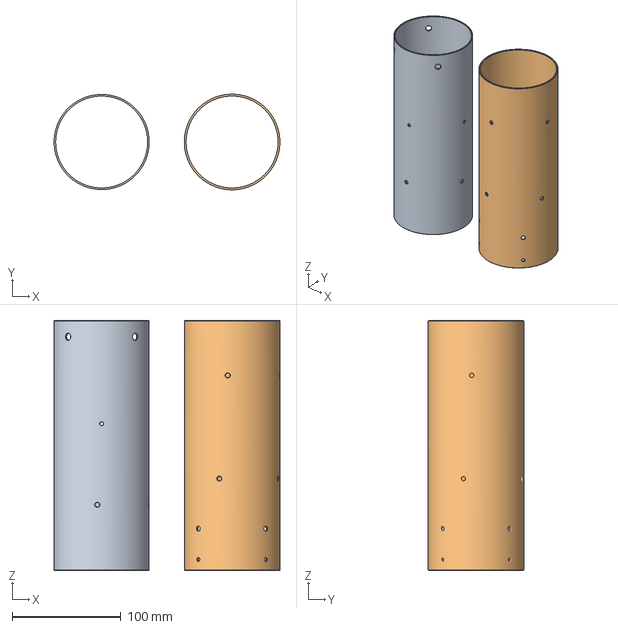
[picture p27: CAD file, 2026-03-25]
2_CAD_Structure/hilfsteile/schablone_bohrungen_oben.3mf
207.8 x 88.0 x 230.0 mm
schablone_bohrungen_oben
schablone_bohrungen_unten

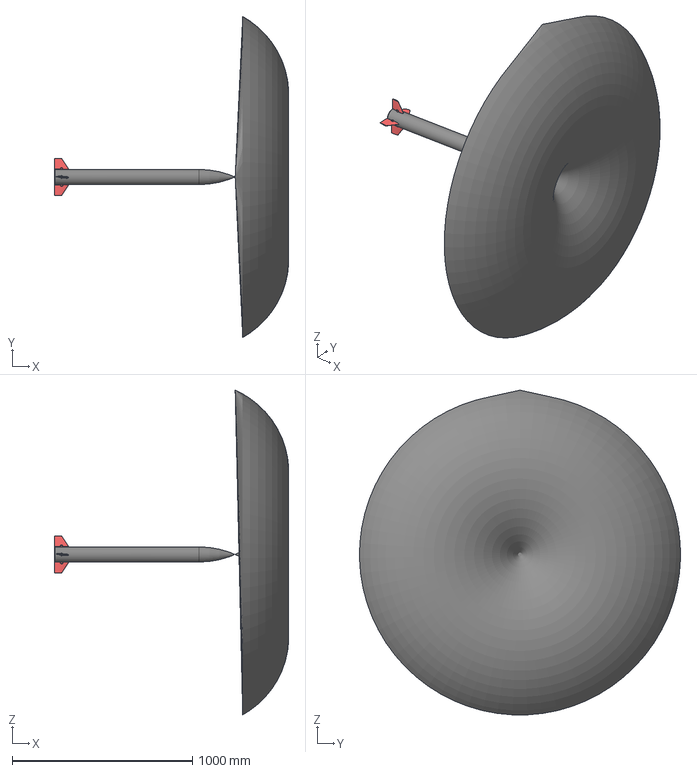
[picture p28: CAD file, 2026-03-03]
2_CAD_Structure/sim/CAD/full_rocket/albert_5_aoa_fins.stp
1299.0 x 1778.7 x 1799.0 mm
fin x 4

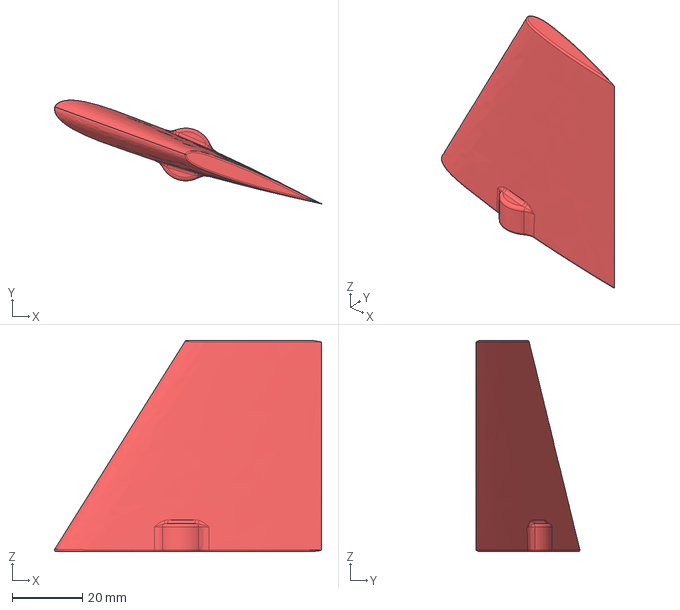
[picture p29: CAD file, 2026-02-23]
2_CAD_Structure/sim/CAD/NACA0012_20_grad.stp
75.8 x 29.5 x 60.0 mm

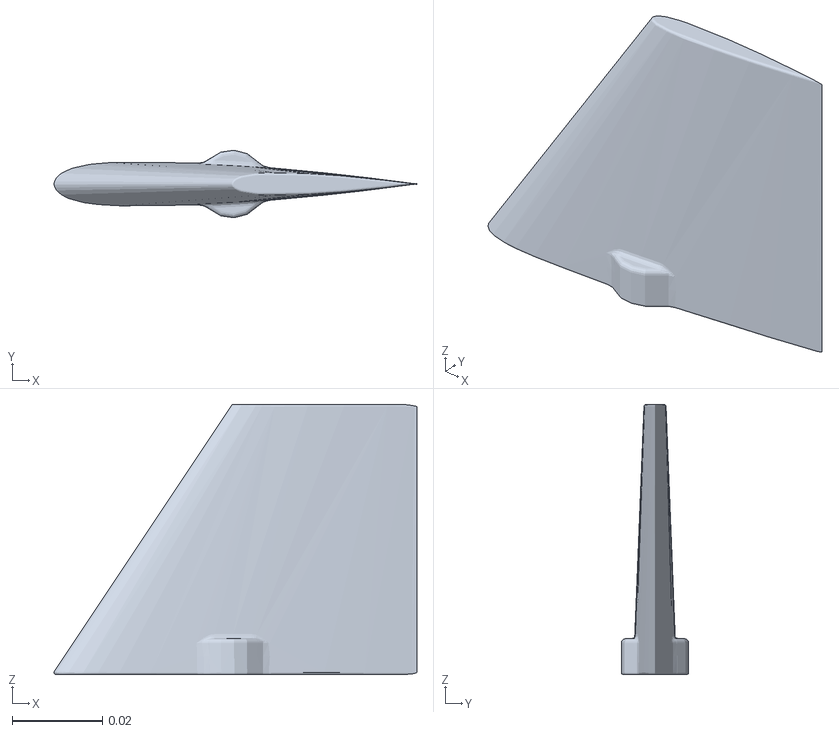
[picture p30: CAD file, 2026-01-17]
2_CAD_Structure/sim/NACA0012/NACA0012_foam/constant/triSurface/NACA0012_SIM_downscaled.stl
0.0806 x 0.015 x 0.06

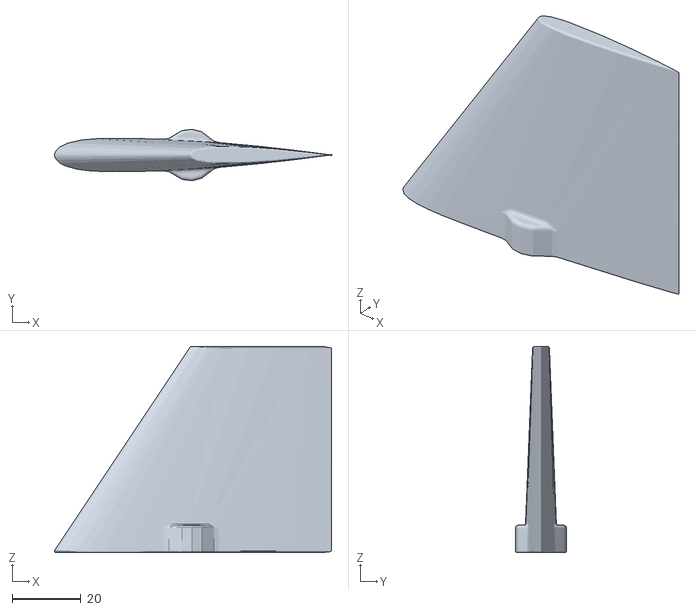
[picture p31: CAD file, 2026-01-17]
2_CAD_Structure/sim/NACA0012/stl/NACA0012_SIM.stl
80.6 x 15.0 x 60.0

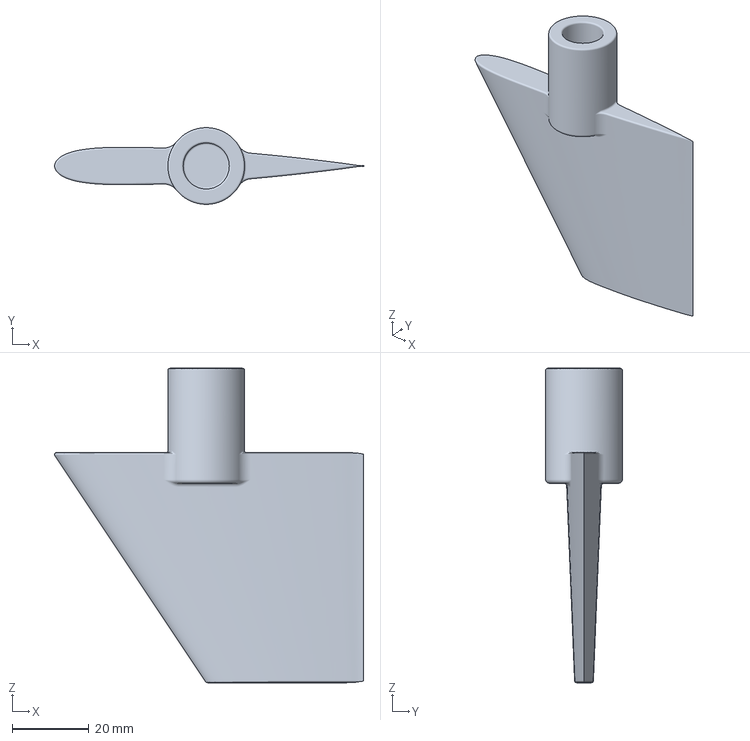
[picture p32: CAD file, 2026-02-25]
2_CAD_Structure/windkanal/finne_windkanal.3mf
80.6 x 20.0 x 82.0 mm

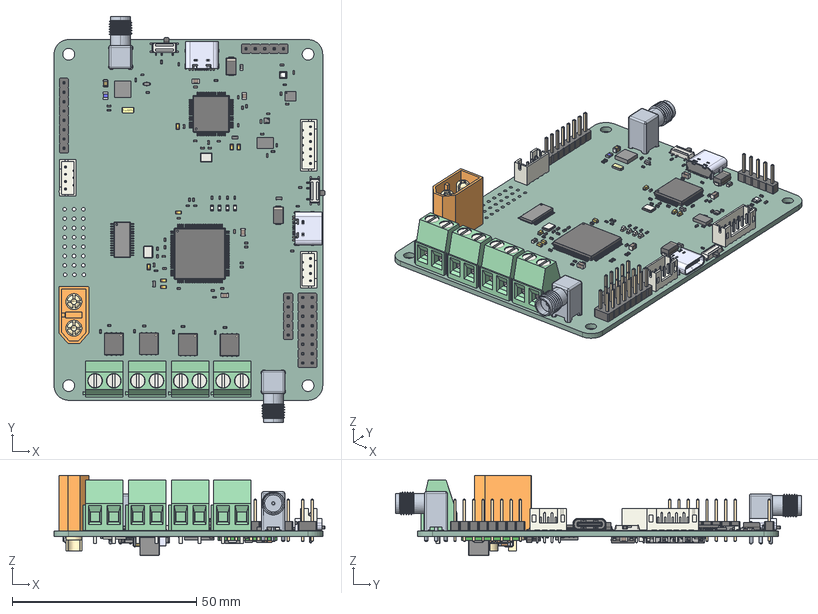
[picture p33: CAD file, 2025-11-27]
3_Flight_Computer/PCB/JLCExport/ALBERT_FLIGHTCOMPUTER.step
73.6 x 110.3 x 21.8 mm
LED_0603_1608Metric x 5
D_SMA x 2
L_0603_1608Metric x 4
R_0402_1005Metric x 46
C_0402_1005Metric x 33
XT60-M
LQFP-64_10x10mm_P0.5mm
TerminalBlock_Phoenix_MKDS-1,5-2-5.08_1x02_P5.08mm_Horizontal x 4
TYPE-C-31-M-12 x 2
TDSON-8-1 x 4
C_0805_2012Metric x 6
CP_EIA-1608-10_AVX-L x 7
BMP390
LQFP-100_14x14mm_P0.5mm
PinsArrayLR
PinHeader_1x05_P2.54mm_Vertical x 2
PinHeader_1x08_P2.54mm_Vertical
PinHeader_2x08_P2.54mm_Vertical
Pins x 2
SW_SPDT_PCM12 x 2
BMM150
JST_PH_B6B-PH-K_1x06_P2.00mm_Vertical
BLM15HD102SN1D
JST_PH_B4B-PH-K_1x04_P2.00mm_Vertical x 2
ESD9R3.3ST5G
Crystal_SMD_3225-4Pin_3.2x2.5mm x 2
CM7V-T1A-32.768KHZ-6PF-20PPM-TA-QC
BMI088
LSM6DSLTR
term1
term2
microSD_HC_Hirose_DM3AT-SF-PEJM5
SOT-23-6
R_2512_6332Metric
SOT-23-8
GRM32ER61C476KE15L
W25N01GVZEIG
Leads
Bar
SOT-223
RFM95W-868S2
ALBERT_FLIGHTCOMPUTER_PCB

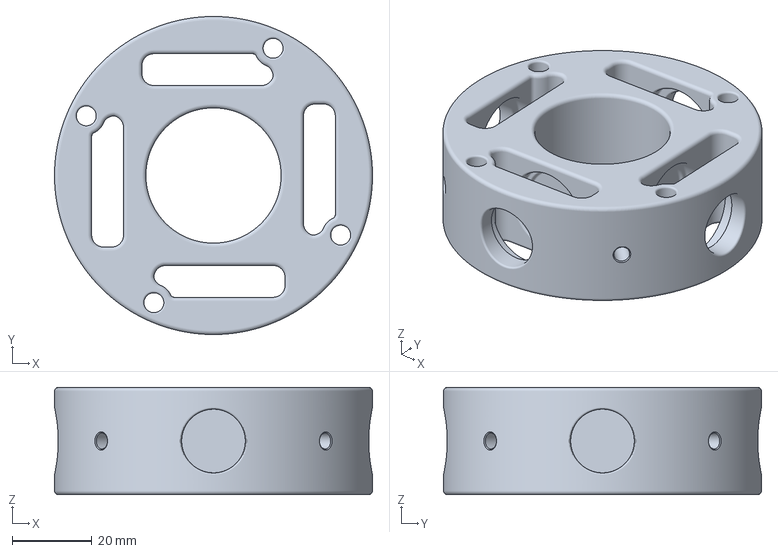
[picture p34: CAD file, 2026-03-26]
2_CAD_Structure/3d_druck/Finnen_Halterung.3mf
80.0 x 80.0 x 27.0 mm

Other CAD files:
2_CAD_Structure/sim/NACA0012_new/NACA0012_foam/constant/triSurface/NACA0012.stl
2_CAD_Structure/sim/NACA0012_new_postGeo/constant/triSurface/NACA0012.stl
2_CAD_Structure/3d_druck/kleine_teile_einzeln/Drehmomentaufnahme_Finne.3mf
2_CAD_Structure/3d_druck_rest/3mf/Kolben.3mf
2_CAD_Structure/3d_druck/Abdeckung_Arsch.3mf
2_CAD_Structure/3d_druck/Abdeckung_Motor_Heck.3mf
2_CAD_Structure/3d_druck/Kleine_Teile.3mf
2_CAD_Structure/3d_druck/Kolben_Abedeckung.3mf
2_CAD_Structure/3d_druck/NACA0012.3mf
2_CAD_Structure/3d_druck/NACA0012_SIM.3mf
2_CAD_Structure/3d_druck/Spitzn_ohne_tip_needs_to_be_pointy.3mf
2_CAD_Structure/3d_druck/kleine_teile_1_mal.3mf
2_CAD_Structure/3d_druck/kleine_teile_einzeln/Abstandhalter_Finne_Servo.3mf
2_CAD_Structure/3d_druck/kleine_teile_einzeln/Abstandhalter_Servo_Komadori_BLYAAAAT.3mf
2_CAD_Structure/3d_druck/kleine_teile_einzeln/Drehmomentaufnahme_Verbindung_Fixed.3mf
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

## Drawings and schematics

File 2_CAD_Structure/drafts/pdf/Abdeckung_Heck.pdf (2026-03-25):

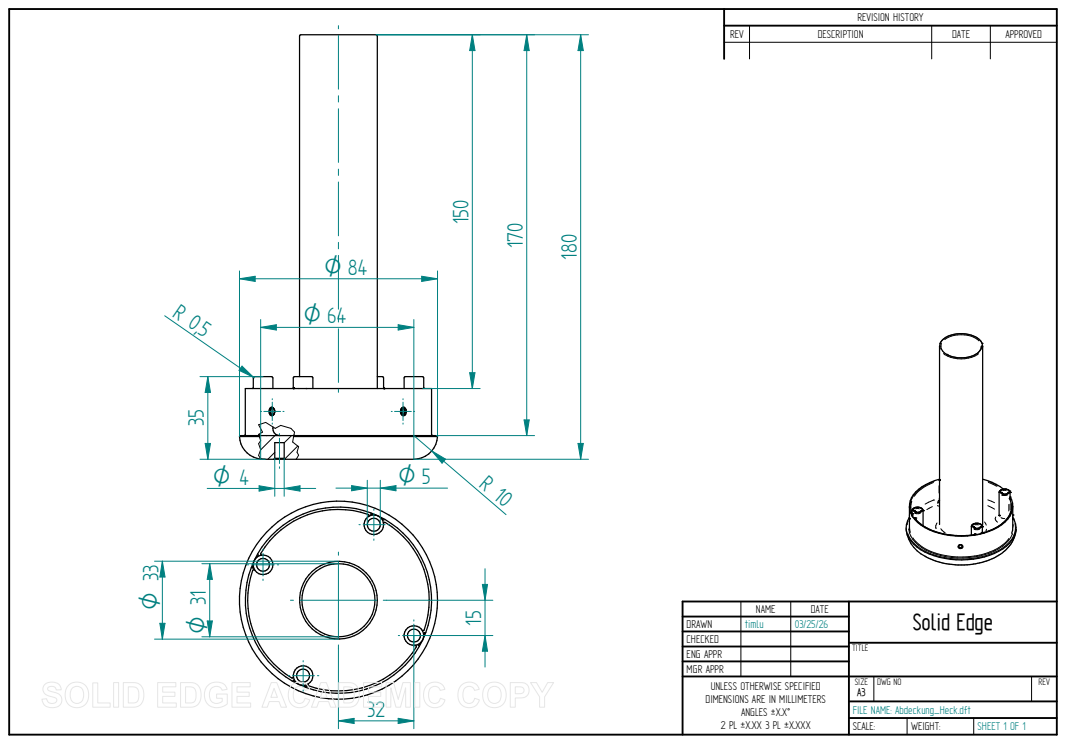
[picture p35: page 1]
TITLE; SCALE:; WEIGHT:; SHEET 1 OF 1; REVISION HISTORY; REV; DESCRIPTION; DATE; APPROVED 180 ¹50

NAME | DATE | Solid Edge

DRAWN | timlu | 03/25/26
CHECKED
ENG APPR
MGR APPR
UNLESS OTHERWISE SPECIFIED DIMENSIONS ARE IN MILLIMETERS ANGLES ±X.X° 2 PL ±X.XX 3 PL ±X.XXX | SIZE A3 | DWG NO | REV

FILE NAME: Abdeckung_Heck.dft

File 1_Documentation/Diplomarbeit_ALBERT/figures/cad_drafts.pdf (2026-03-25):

TITLE; SCALE:; WEIGHT:; SHEET 1 OF 1; REVISION HISTORY; REV; DESCRIPTION; DATE; APPROVED 180 ¹50

NAME | DATE | Solid Edge

DRAWN | timlu | 03/25/26
CHECKED
ENG APPR
MGR APPR
UNLESS OTHERWISE SPECIFIED DIMENSIONS ARE IN MILLIMETERS ANGLES ±X.X° 2 PL ±X.XX 3 PL ±X.XXX | SIZE A3 | DWG NO | REV

FILE NAME: Abdeckung_Heck.dft

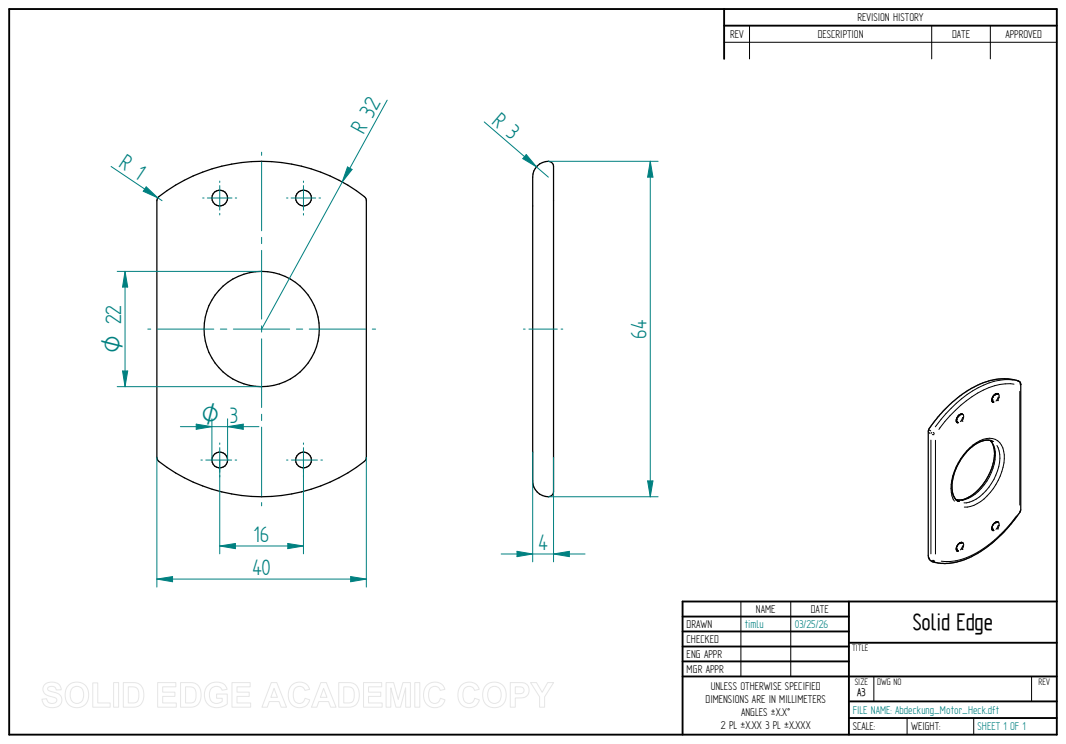
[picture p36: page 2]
TITLE; REV; DESCRIPTION; DATE; APPROVED

NAME | DATE | Solid Edge

DRAWN | timlu | 03/25/26
CHECKED
ENG APPR
MGR APPR
UNLESS OTHERWISE SPECIFIED | SIZE A3 | DWG NO | REV

FILE NAME: Abdeckung_Motor_Heck.dft

16 27

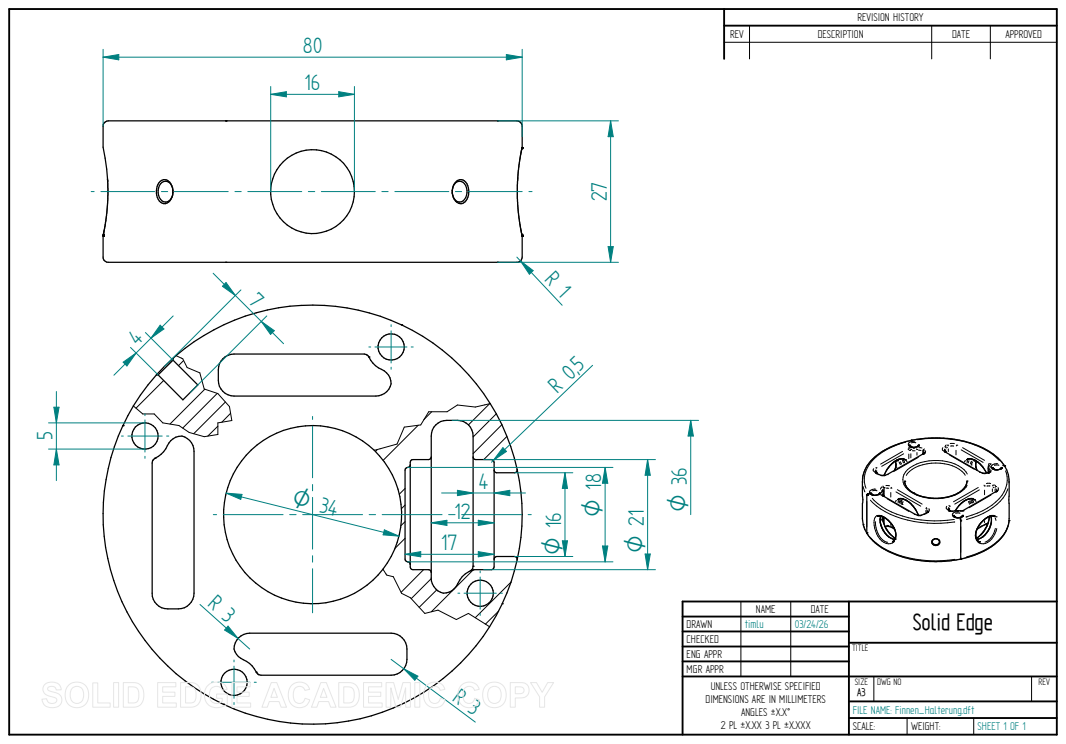
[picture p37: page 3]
TITLE; REV; DESCRIPTION; DATE; APPROVED 80

NAME | DATE | Solid Edge

DRAWN | timlu | 03/24/26
CHECKED
ENG APPR
MGR APPR
UNLESS OTHERWISE SPECIFIED | SIZE A3 | DWG NO | REV

FILE NAME: Finnen_Halterung.dft

80 45

O 2,4 34,1 10,9 15

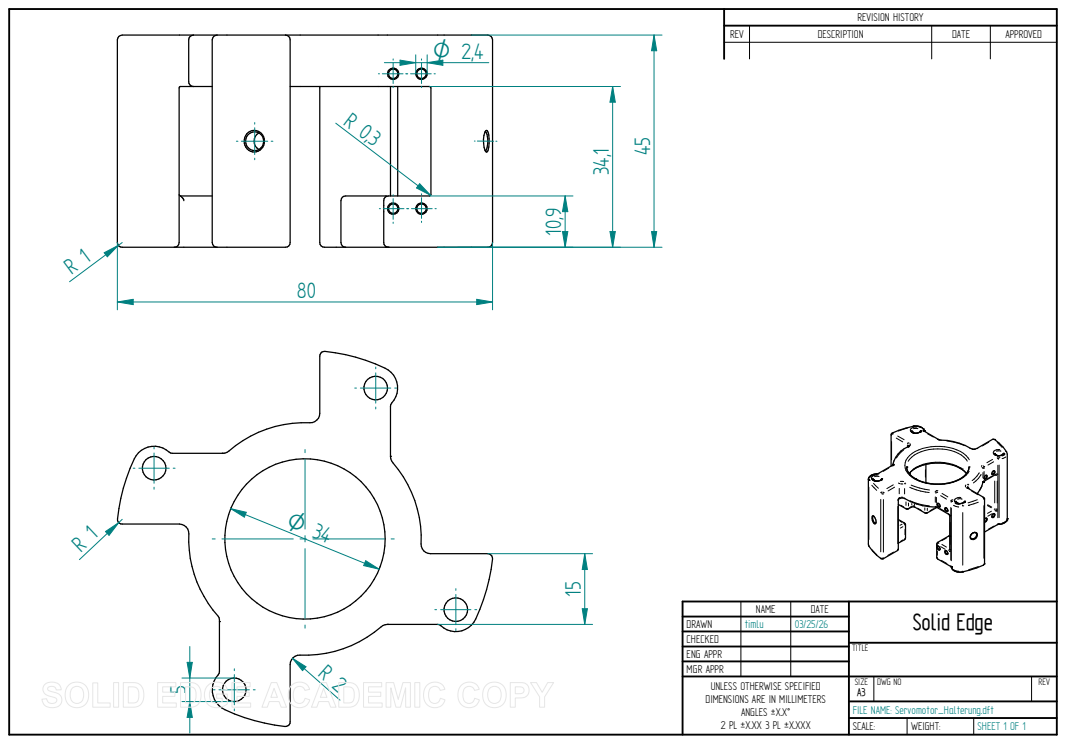
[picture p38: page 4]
TITLE

NAME | DATE | Solid Edge

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

FILE NAME: Servomotor_Halterung.dft

O 2

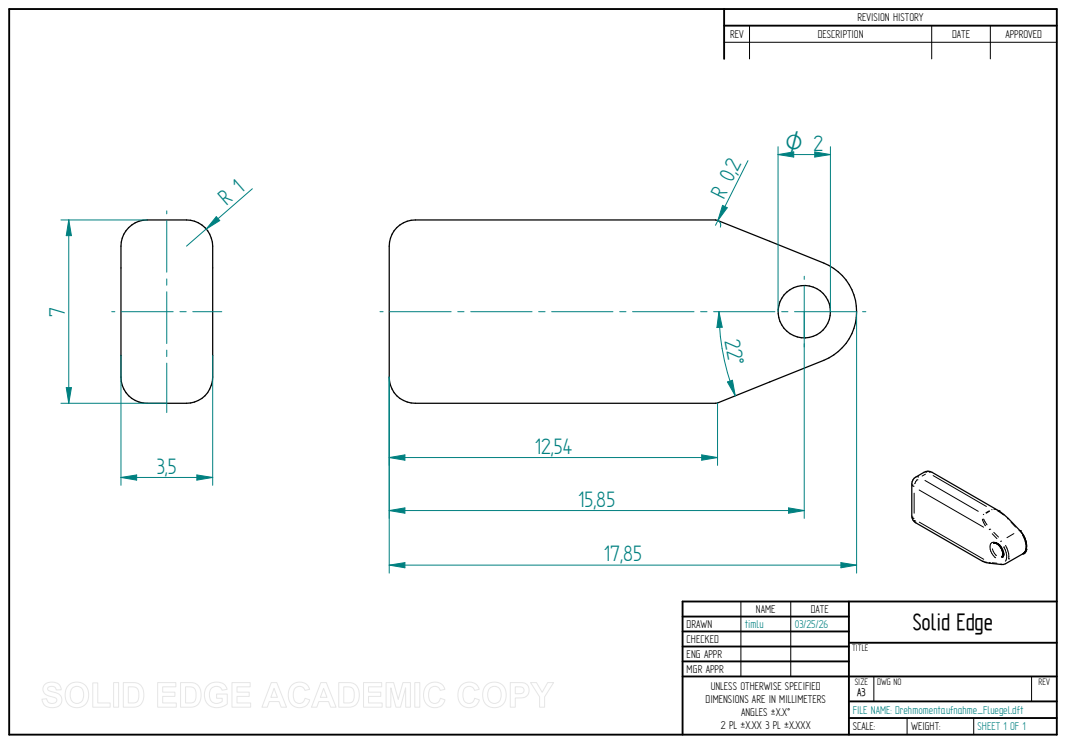
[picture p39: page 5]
TITLE

NAME | DATE | Solid Edge

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

FILE NAME: Drehmomentaufnahme_Fluegel.dft

7 10,8⁵

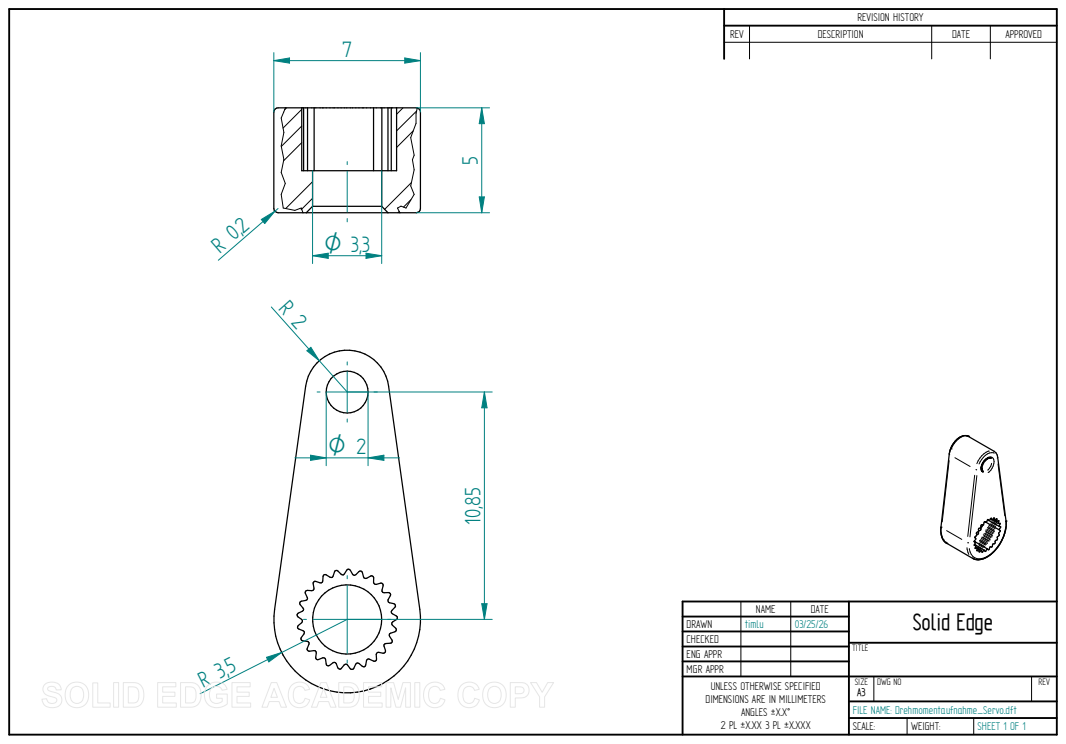
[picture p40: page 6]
TITLE

NAME | DATE | Solid Edge

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

FILE NAME: Drehmomentaufnahme_Servo.dft

5

O 2

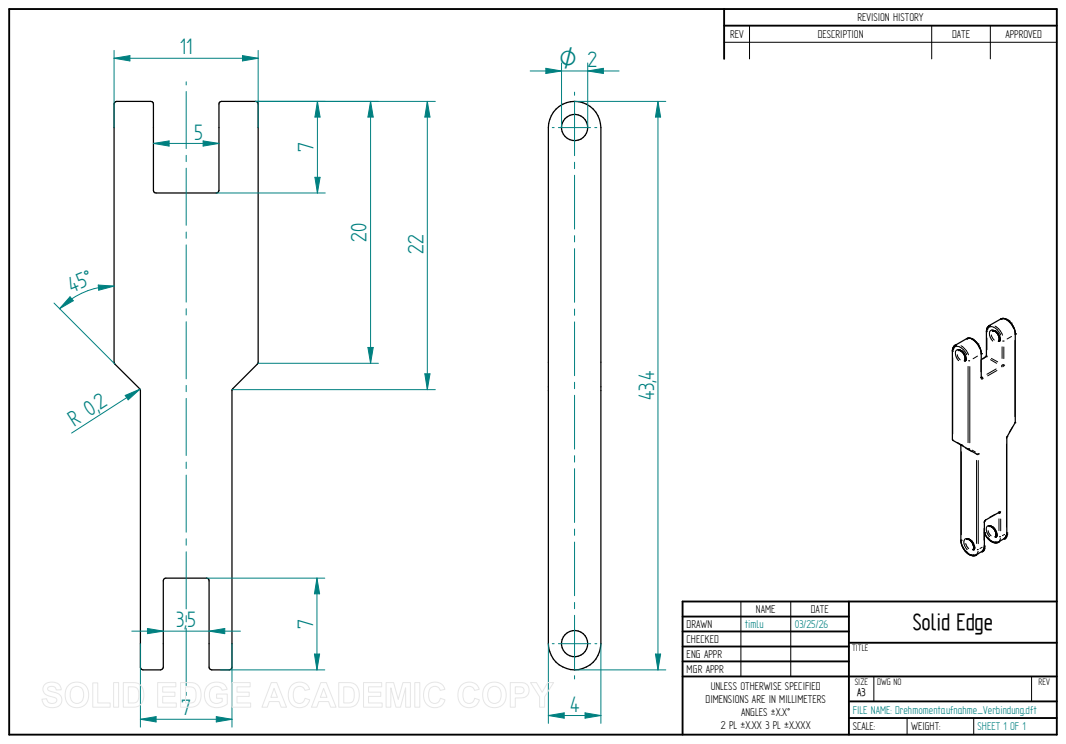
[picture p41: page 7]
TITLE

NAME | DATE | Solid Edge

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

FILE NAME: Drehmomentaufnahme_Verbindung.dft

5
40

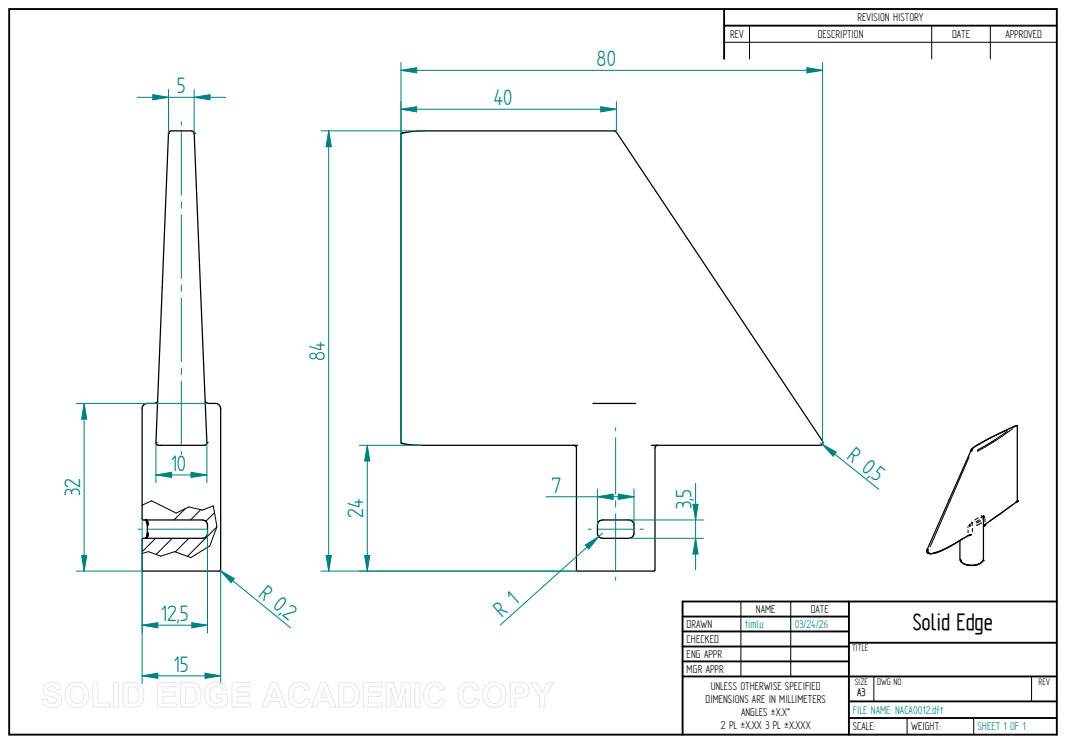
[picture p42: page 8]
TITLE

NAME | DATE | Solid Edge

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

FILE NAME: NACA0012.dft

57,18 13,8

18 10

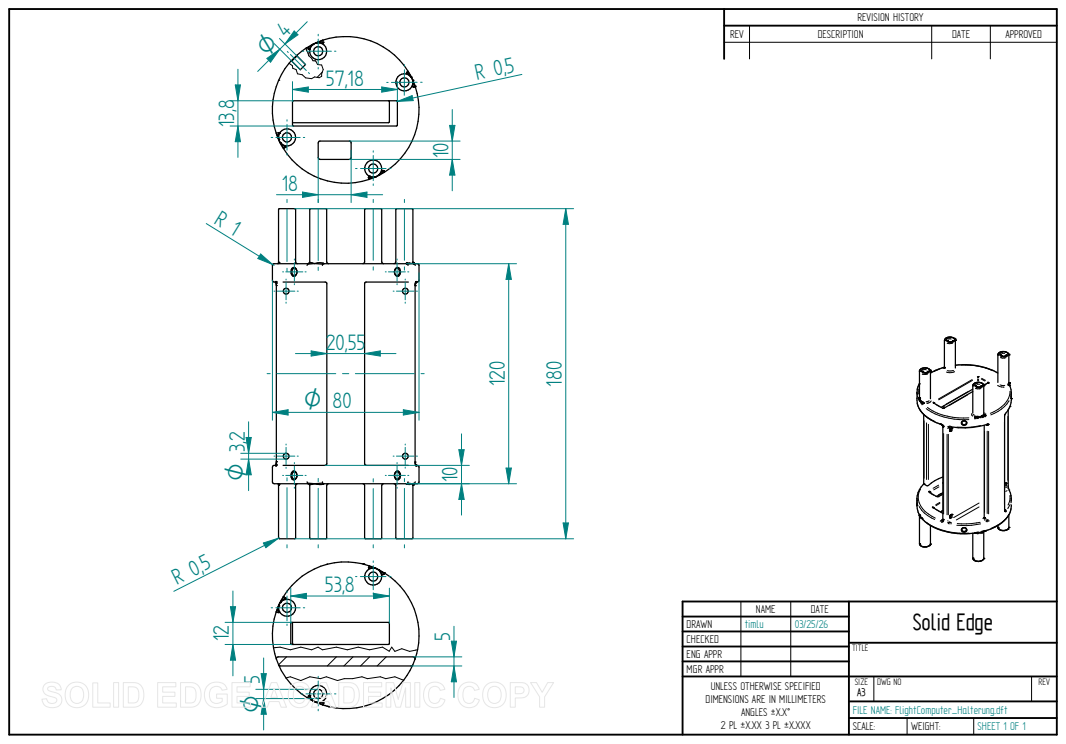
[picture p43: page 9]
TITLE

NAME | DATE | Solid Edge

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

FILE NAME: FlightComputer_Halterung.dft

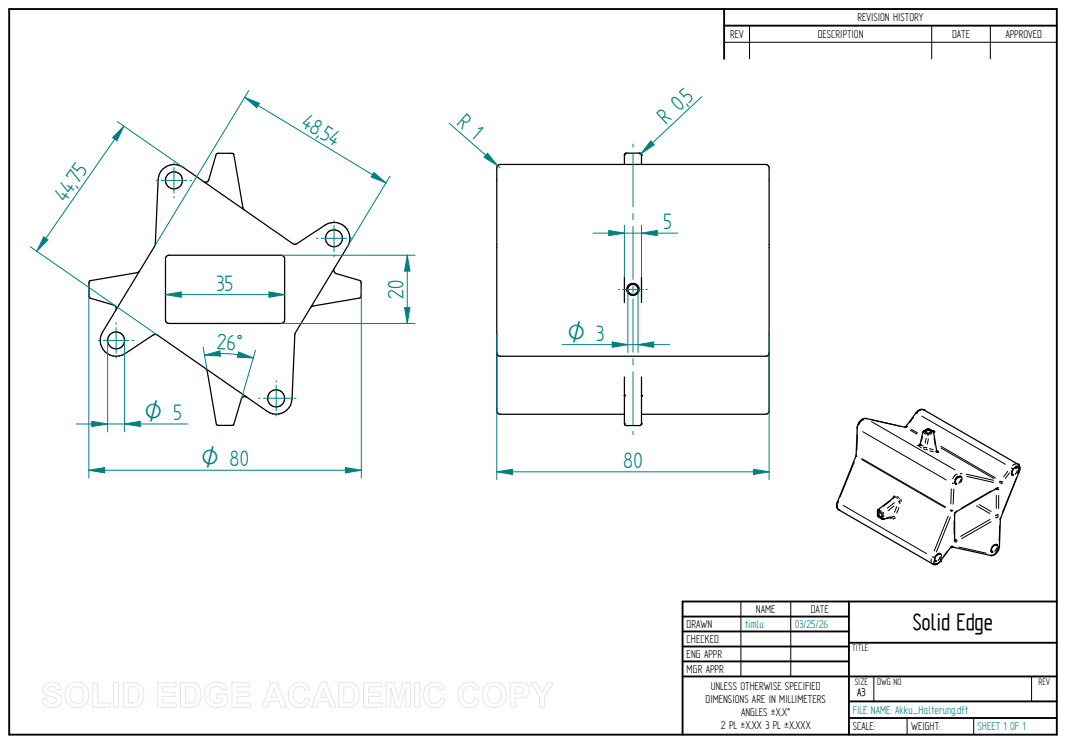
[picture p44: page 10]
TITLE

NAME | DATE | Solid Edge

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

FILE NAME: Akku_Halterung.dft

60

30 10

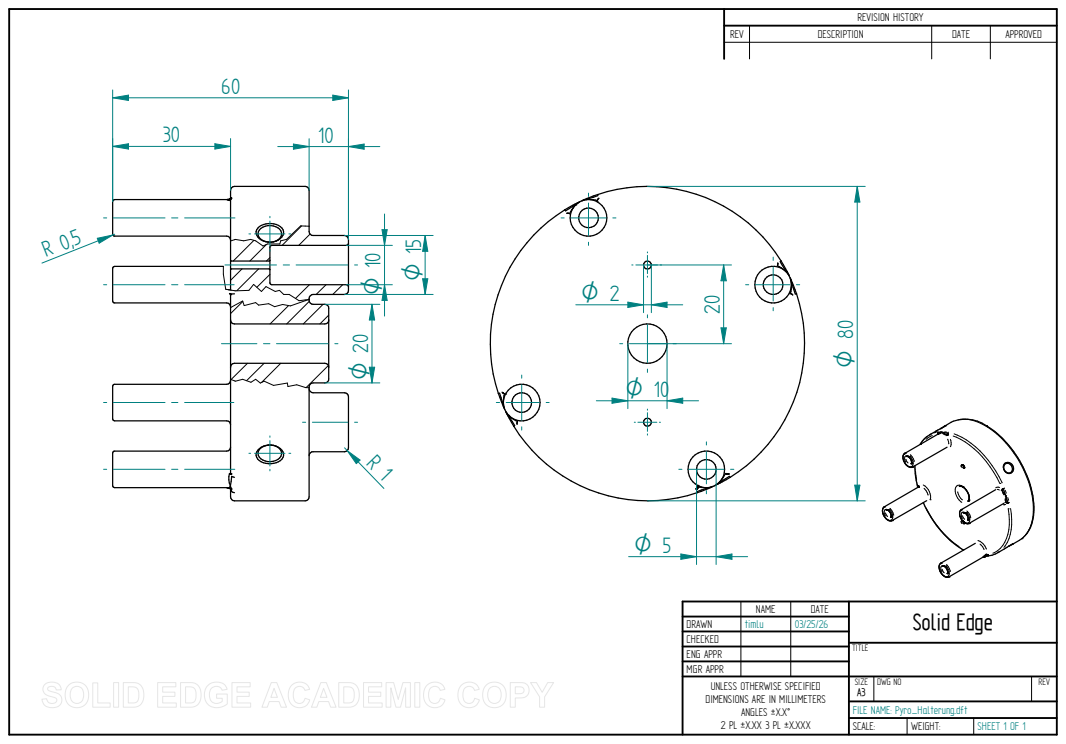
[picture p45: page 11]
TITLE

NAME | DATE | Solid Edge

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

FILE NAME: Pyro_Halterung.dft

O 70

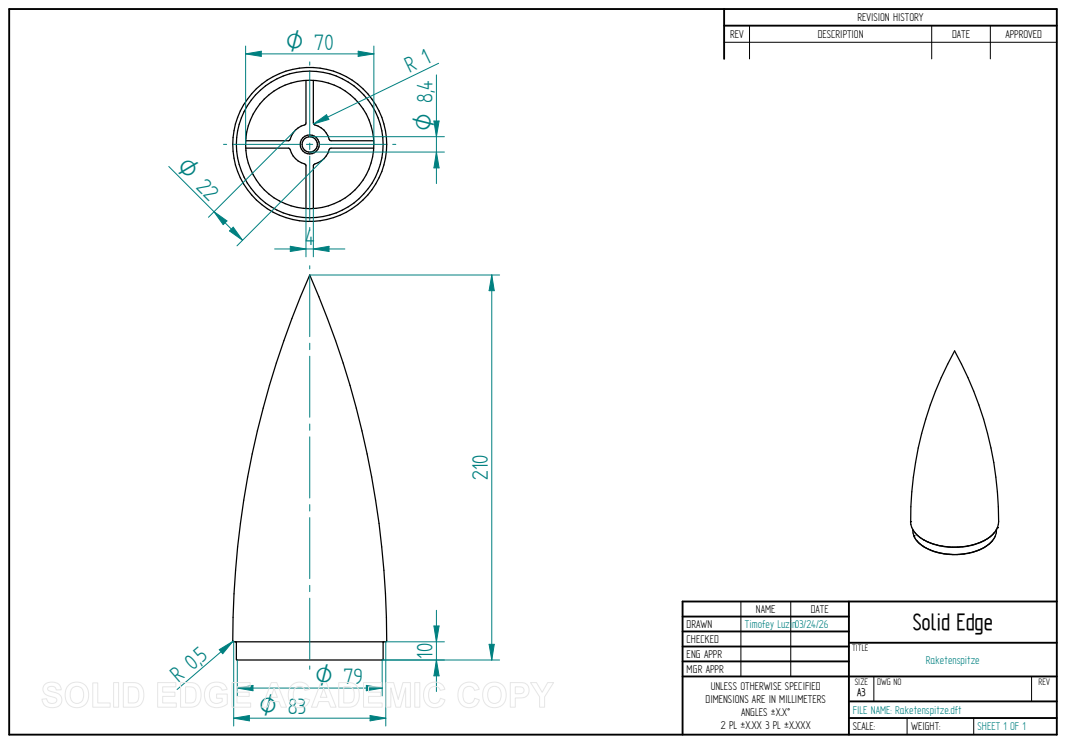
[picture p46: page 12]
TITLE; Raketenspitze; REV; DESCRIPTION; DATE; APPROVED 2¹0 10 8,4

NAME | DATE | Solid Edge

DRAWN | Timofey Luzin | 03/24/26
CHECKED
ENG APPR
MGR APPR
UNLESS OTHERWISE SPECIFIED | SIZE A3 | DWG NO | REV

FILE NAME: Raketenspitze.dft

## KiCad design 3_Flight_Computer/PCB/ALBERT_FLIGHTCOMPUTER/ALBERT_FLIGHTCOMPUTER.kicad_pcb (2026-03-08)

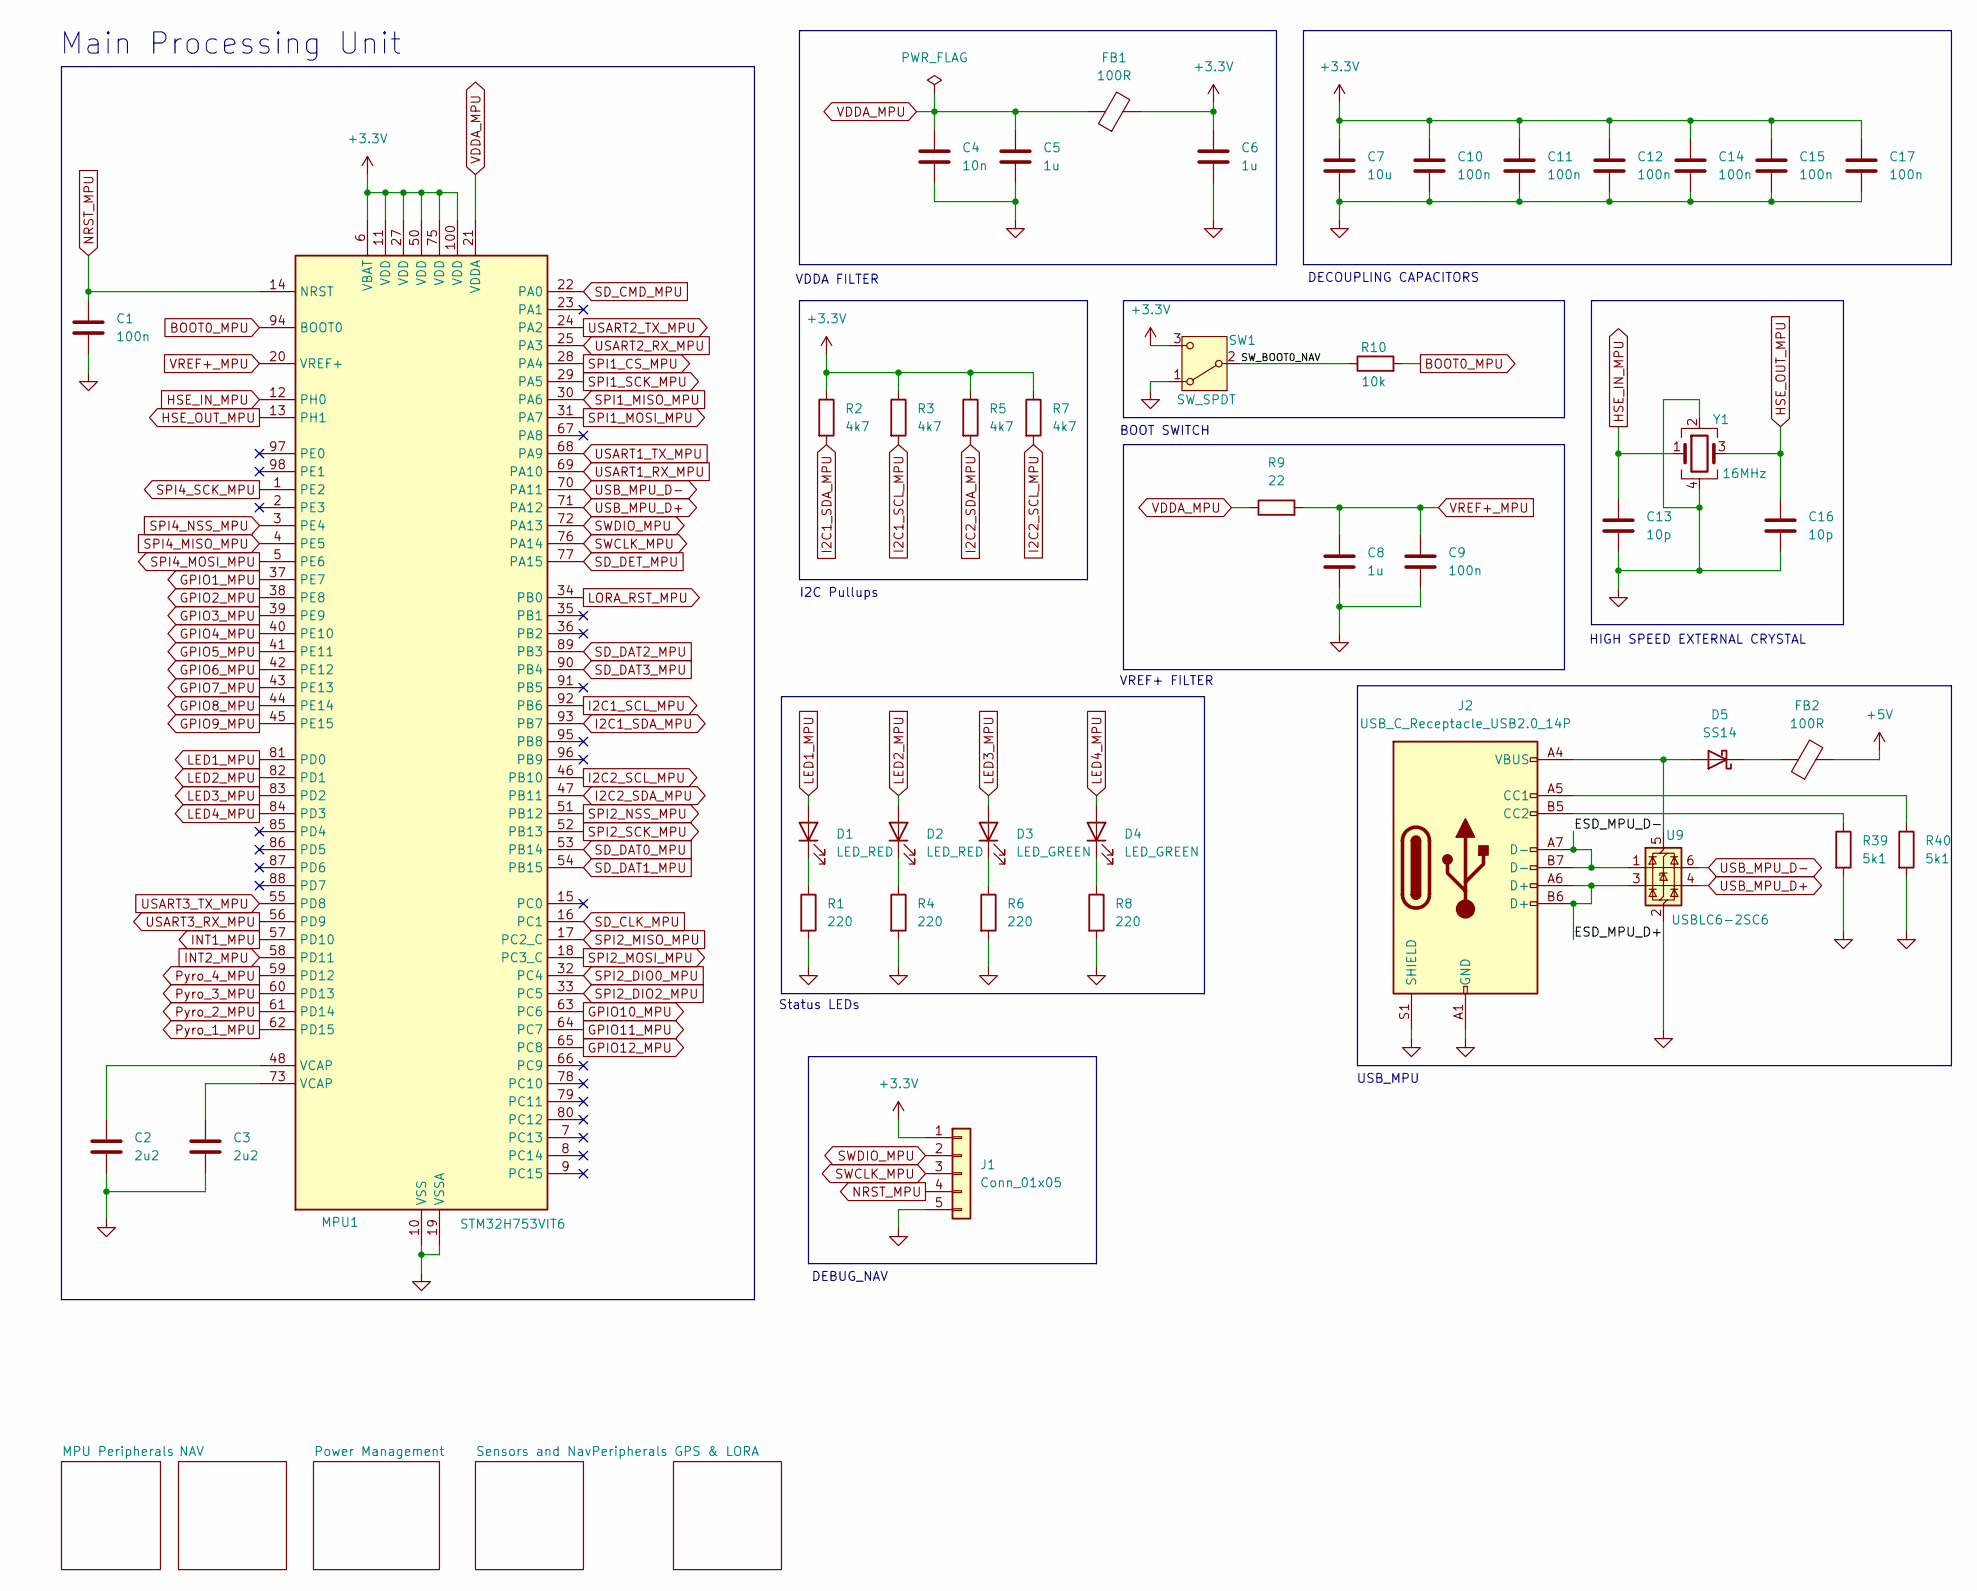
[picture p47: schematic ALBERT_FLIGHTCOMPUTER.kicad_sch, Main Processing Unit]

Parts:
C1, C9, C10, C11, C12, C14, C15, C17: 100n; C_0402_1005Metric; LCSC C1525
C2, C3: 2u2; C_0805_2012Metric; LCSC C377773
C4: 10n; C_0402_1005Metric; LCSC C15195
C5, C6, C8: 1u; C_0805_2012Metric; LCSC C28323
C7: 10u; C_0805_2012Metric; LCSC C15850
C13, C16: 10p; C_0402_1005Metric; LCSC C32949
D1, D2: LED_RED; LED_0603_1608Metric
D3, D4: LED_GREEN; LED_0603_1608Metric
D5: SS14; D_SMA; LCSC C2480
FB1: 100R; L_0603_1608Metric; LCSC C15957
FB2: 100R; L_0805_2012Metric; LCSC C15957
J1: Conn_01x05; PinHeader_1x05_P2.54mm_Vertical
J2: USB_C_Receptacle_USB2.0_14P; USB_C_Receptacle_HRO_TYPE-C-31-M-12; LCSC C165948
MPU1: STM32H753VIT6; LQFP-100_14x14mm_P0.5mm; Manufacturer Part Number STM32H753VIT6; LCSC C730206
R1, R4, R6, R8: 220; R_0402_1005Metric; LCSC C25091
R2, R3, R5, R7: 4k7; R_0402_1005Metric; LCSC C25900
R9: 22; R_0402_1005Metric; LCSC C25092
R10: 10k; R_0402_1005Metric; LCSC C25744
R39, R40: 5k1; R_0402_1005Metric; LCSC C25905
SW1: SW_SPDT; SW_SPDT_PCM12; LCSC C221841
U9: USBLC6-2SC6; SOT-23-6; LCSC C7519
Y1: 16MHz; Crystal_SMD_3225-4Pin_3.2x2.5mm; LCSC C13738

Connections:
+3.3V: C6.1, C7.1, C10.1, C11.1, C12.1, C14.1, C15.1, C17.1, FB1.2, J1.1, MPU1.6 (VBAT), MPU1.11 (VDD), MPU1.27 (VDD), MPU1.50 (VDD), MPU1.75 (VDD), MPU1.100 (VDD), R2.1, R3.1, R5.1, R7.1, SW1.3 (C); also elsewhere on the board
+5V: FB2.2; also elsewhere on the board
/ESD_MPU_D+: J2.A6 (D+), J2.B6 (D+), U9.3 (I/O2)
/ESD_MPU_D-: J2.A7 (D-), J2.B7 (D-), U9.1 (I/O1)
/SW_BOOT0_NAV: R10.1, SW1.2 (B)
BOOT0_MPU: MPU1.94 (BOOT0), R10.2
GND: C1.2, C2.2, C3.2, C4.2, C5.2, C6.2, C7.2, C8.2, C9.2, C10.2, C11.2, C12.2, C13.2, C14.2, C15.2, C16.2, C17.2, J1.5, J2.A1 (GND), J2.A12 (GND), J2.B1 (GND), J2.B12 (GND), J2.S1 (SHIELD), MPU1.10 (VSS), MPU1.19 (VSSA), MPU1.26 (VSS), MPU1.49 (VSS), MPU1.74 (VSS), MPU1.99 (VSS), R1.2, R4.2, R6.2, R8.2, R39.2, R40.2, SW1.1 (A), U9.2 (GND), Y1.2, Y1.4; also elsewhere on the board
GPIO1_MPU: MPU1.37 (PE7); also elsewhere on the board
GPIO2_MPU: MPU1.38 (PE8); also elsewhere on the board
GPIO3_MPU: MPU1.39 (PE9); also elsewhere on the board
GPIO4_MPU: MPU1.40 (PE10); also elsewhere on the board
GPIO5_MPU: MPU1.41 (PE11); also elsewhere on the board
GPIO6_MPU: MPU1.42 (PE12); also elsewhere on the board
GPIO7_MPU: MPU1.43 (PE13); also elsewhere on the board
GPIO8_MPU: MPU1.44 (PE14); also elsewhere on the board
GPIO9_MPU: MPU1.45 (PE15); also elsewhere on the board
GPIO10_MPU: MPU1.63 (PC6); also elsewhere on the board
GPIO11_MPU: MPU1.64 (PC7); also elsewhere on the board
GPIO12_MPU: MPU1.65 (PC8); also elsewhere on the board
HSE_IN_MPU: C13.1, MPU1.12 (PH0), Y1.1
HSE_OUT_MPU: C16.1, MPU1.13 (PH1), Y1.3
I2C1_SCL_MPU: MPU1.92 (PB6), R3.2; also elsewhere on the board
I2C1_SDA_MPU: MPU1.93 (PB7), R2.2; also elsewhere on the board
I2C2_SCL_MPU: MPU1.46 (PB10), R7.2; also elsewhere on the board
I2C2_SDA_MPU: MPU1.47 (PB11), R5.2; also elsewhere on the board
INT1_MPU: MPU1.57 (PD10); also elsewhere on the board
INT2_MPU: MPU1.58 (PD11); also elsewhere on the board
LED1_MPU: D1.2 (A), MPU1.81 (PD0)
LED2_MPU: D2.2 (A), MPU1.82 (PD1)
LED3_MPU: D3.2 (A), MPU1.83 (PD2)
LED4_MPU: D4.2 (A), MPU1.84 (PD3)
LORA_RST_MPU: MPU1.34 (PB0); also elsewhere on the board
NRST_MPU: C1.1, J1.4, MPU1.14 (NRST)
unnamed: C2.1, MPU1.48 (VCAP)
unnamed: C3.1, MPU1.73 (VCAP)
unnamed: D1.1 (K), R1.1
unnamed: D2.1 (K), R4.1
unnamed: D3.1 (K), R6.1
unnamed: D4.1 (K), R8.1
unnamed: D5.2 (A), J2.A4 (VBUS), J2.A9 (VBUS), J2.B4 (VBUS), J2.B9 (VBUS), U9.5 (VBUS)
unnamed: D5.1 (K), FB2.1
unnamed: J2.A5 (CC1), R40.1
unnamed: J2.B5 (CC2), R39.1
Pyro_1_MPU: MPU1.62 (PD15); also elsewhere on the board
Pyro_2_MPU: MPU1.61 (PD14); also elsewhere on the board
Pyro_3_MPU: MPU1.60 (PD13); also elsewhere on the board
Pyro_4_MPU: MPU1.59 (PD12); also elsewhere on the board
SD_CLK_MPU: MPU1.16 (PC1); also elsewhere on the board
SD_CMD_MPU: MPU1.22 (PA0); also elsewhere on the board
SD_DAT0_MPU: MPU1.53 (PB14); also elsewhere on the board
SD_DAT1_MPU: MPU1.54 (PB15); also elsewhere on the board
SD_DAT2_MPU: MPU1.89 (PB3); also elsewhere on the board
SD_DAT3_MPU: MPU1.90 (PB4); also elsewhere on the board
SD_DET_MPU: MPU1.77 (PA15); also elsewhere on the board
SPI1_CS_MPU: MPU1.28 (PA4); also elsewhere on the board
SPI1_MISO_MPU: MPU1.30 (PA6); also elsewhere on the board
SPI1_MOSI_MPU: MPU1.31 (PA7); also elsewhere on the board
SPI1_SCK_MPU: MPU1.29 (PA5); also elsewhere on the board
SPI2_DIO0_MPU: MPU1.32 (PC4); also elsewhere on the board
SPI2_DIO2_MPU: MPU1.33 (PC5); also elsewhere on the board
SPI2_MISO_MPU: MPU1.17 (PC2_C); also elsewhere on the board
SPI2_MOSI_MPU: MPU1.18 (PC3_C); also elsewhere on the board
SPI2_NSS_MPU: MPU1.51 (PB12); also elsewhere on the board
SPI2_SCK_MPU: MPU1.52 (PB13); also elsewhere on the board
SPI4_MISO_MPU: MPU1.4 (PE5); also elsewhere on the board
SPI4_MOSI_MPU: MPU1.5 (PE6); also elsewhere on the board
SPI4_NSS_MPU: MPU1.3 (PE4); also elsewhere on the board
SPI4_SCK_MPU: MPU1.1 (PE2); also elsewhere on the board
SWCLK_MPU: J1.3, MPU1.76 (PA14)
SWDIO_MPU: J1.2, MPU1.72 (PA13)
USART1_RX_MPU: MPU1.69 (PA10); also elsewhere on the board
USART1_TX_MPU: MPU1.68 (PA9); also elsewhere on the board
USART2_RX_MPU: MPU1.25 (PA3); also elsewhere on the board
USART2_TX_MPU: MPU1.24 (PA2); also elsewhere on the board
USART3_RX_MPU: MPU1.56 (PD9); also elsewhere on the board
USART3_TX_MPU: MPU1.55 (PD8); also elsewhere on the board
USB_MPU_D+: MPU1.71 (PA12), U9.4 (I/O2)
USB_MPU_D-: MPU1.70 (PA11), U9.6 (I/O1)
VDDA_MPU: C4.1, C5.1, FB1.1, MPU1.21 (VDDA), R9.1
VREF+_MPU: C8.1, C9.1, MPU1.20 (VREF+), R9.2

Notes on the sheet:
USB_MPU
BOOT SWITCH
VDDA FILTER
Main Processing Unit
VREF+ FILTER
I2C Pullups
DEBUG_NAV
HIGH SPEED EXTERNAL CRYSTAL
Status LEDs
DECOUPLING CAPACITORS

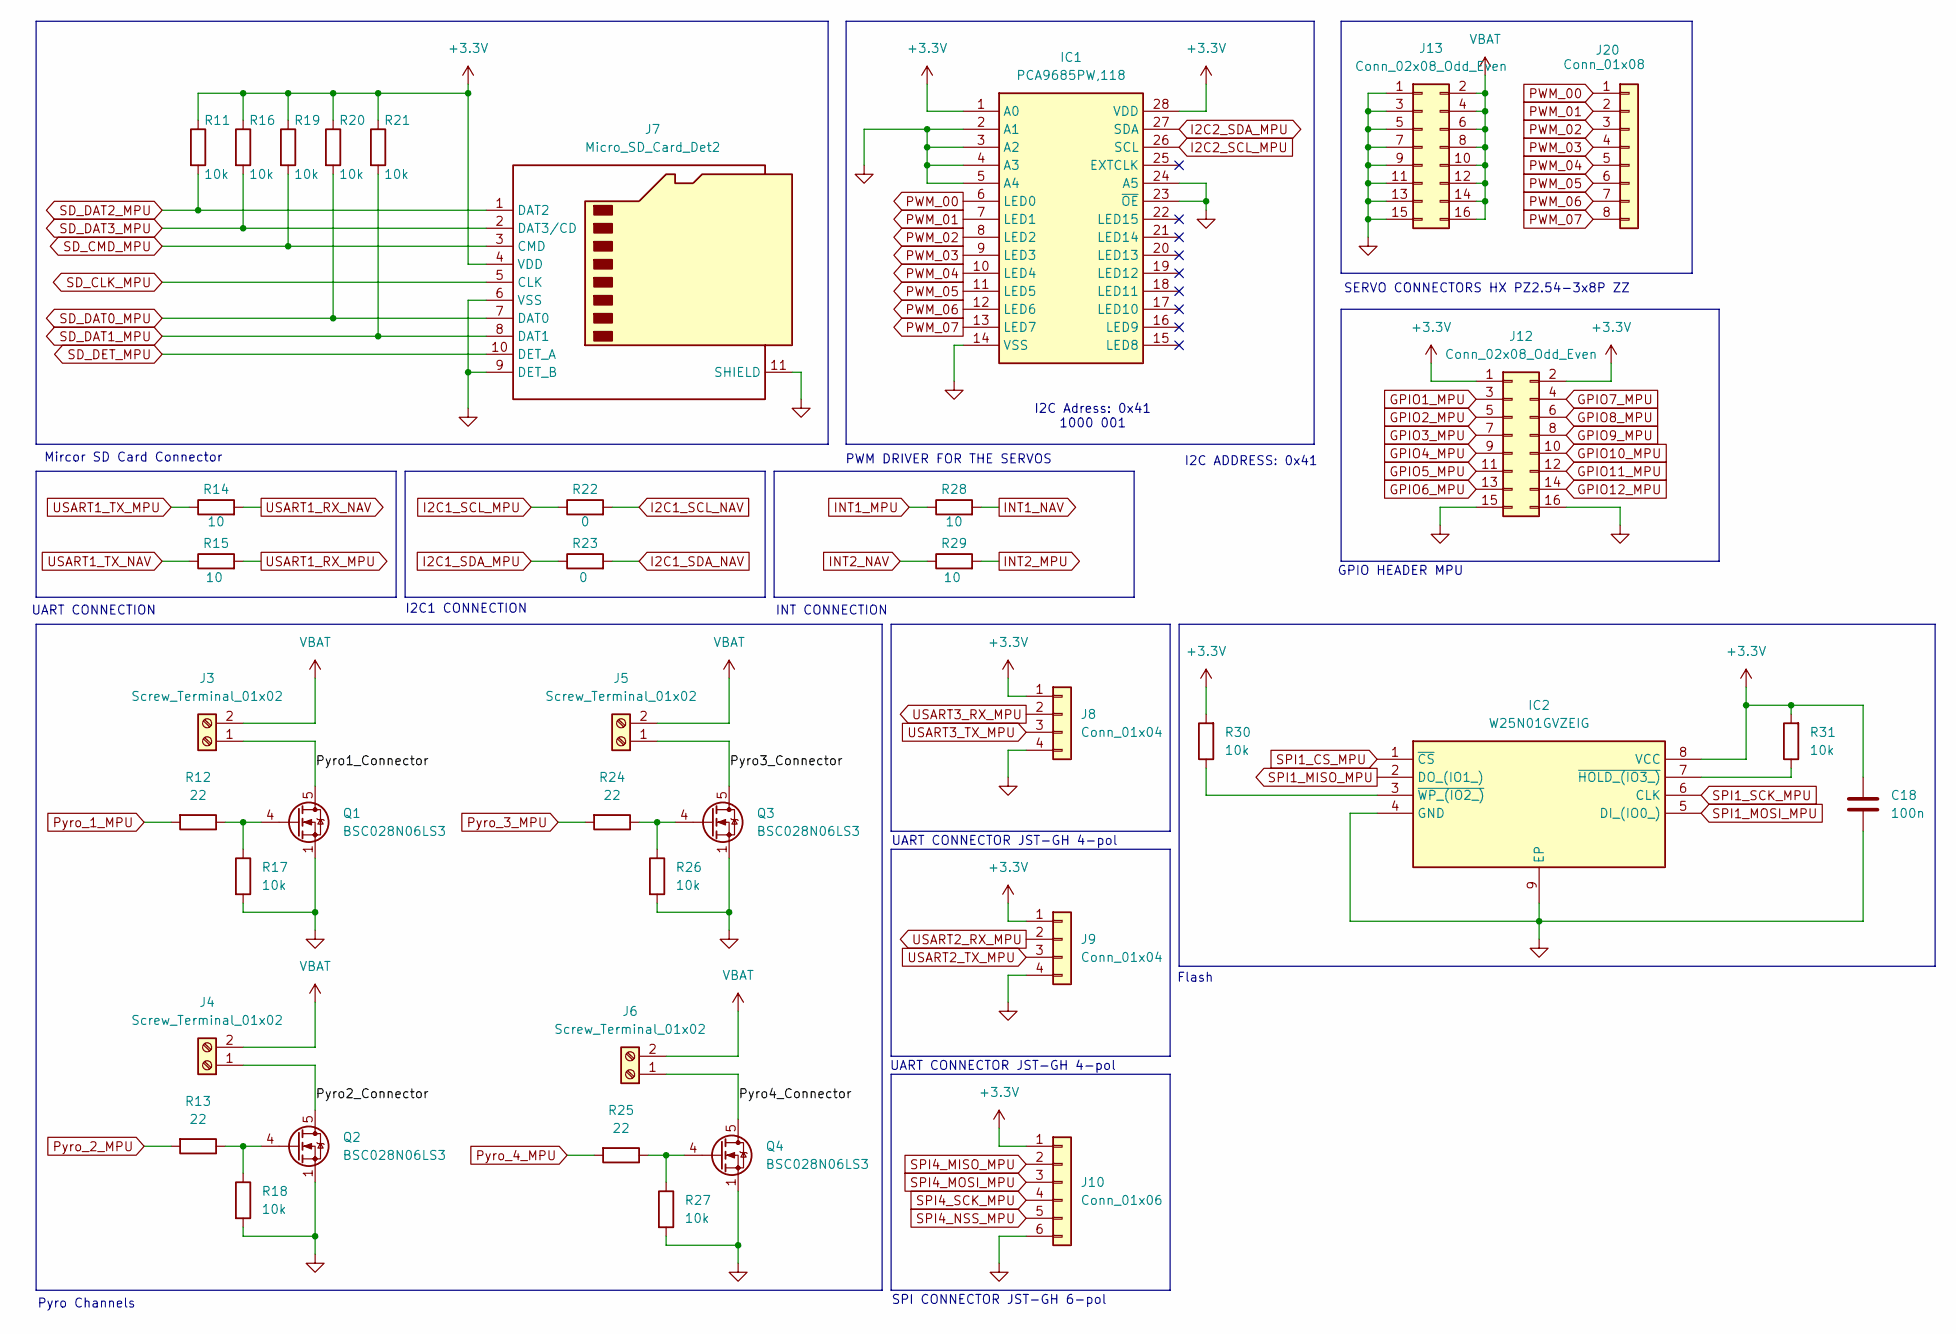
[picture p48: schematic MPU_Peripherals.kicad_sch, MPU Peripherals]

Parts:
C18: 100n; C_0402_1005Metric; LCSC C1525
IC1: PCA9685PW,118; SOP65P640X110-28N; Mouser Part Number 771-PCA9685PW,118
IC2: W25N01GVZEIG; SON127P800X600X80-9N-D; Mouser Part Number 454-W25N01GVZEIG
J3, J4, J5, J6: Screw_Terminal_01x02; TerminalBlock_Phoenix_MKDS-1,5-2-5.08_1x02_P5.08mm_Horizont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; LCSC C5183989
J7: Micro_SD_Card_Det2; microSD_HC_Hirose_DM3AT-SF-PEJM5; LCSC C114218
J8, J9: Conn_01x04; JST_PH_B4B-PH-K_1x04_P2.00mm_Vertical; LCSC C566011
J10: Conn_01x06; JST_PH_B6B-PH-K_1x06_P2.00mm_Vertical; LCSC C495261
J12, J13: Conn_02x08_Odd_Even; PinHeader_2x08_P2.54mm_Vertical
J20: Conn_01x08; PinHeader_1x08_P2.54mm_Vertical
Q1, Q2, Q3, Q4: BSC028N06LS3; TDSON-8-1; LCSC C534316
R11, R16, R17, R18, R19, R20, R21, R26, R27, R30, R31: 10k; R_0402_1005Metric; LCSC C25744
R12, R13, R24, R25: 22; R_0402_1005Metric; LCSC C25092
R14, R15, R28, R29: 10; R_0402_1005Metric; LCSC C25077
R22, R23: 0; R_0402_1005Metric; LCSC C17168

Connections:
+3.3V: C18.1, IC1.1 (A0), IC1.28 (VDD), IC2.8 (VCC), J7.4 (VDD), J8.1, J9.1, J10.1, J12.1, J12.2, R11.1, R16.1, R19.1, R20.1, R21.1, R30.2, R31.2; also elsewhere on the board
/MPU Peripherals/Pyro1_Connector: J3.1, Q1.5 (D)
/MPU Peripherals/Pyro2_Connector: J4.1, Q2.5 (D)
/MPU Peripherals/Pyro3_Connector: J5.1, Q3.5 (D)
/MPU Peripherals/Pyro4_Connector: J6.1, Q4.5 (D)
GND: C18.2, IC1.2 (A1), IC1.3 (A2), IC1.4 (A3), IC1.5 (A4), IC1.14 (VSS), IC1.23 (~OE), IC1.24 (A5), IC2.4 (GND), IC2.9 (EP), J7.6 (VSS), J7.9 (DET_B), J7.11 (SHIELD), J8.4, J9.4, J10.6, J12.15, J12.16, J13.1, J13.3, J13.5, J13.7, J13.9, J13.11, J13.13, J13.15, Q1.1 (S), Q1.2 (S), Q1.3 (S), Q2.1 (S), Q2.2 (S), Q2.3 (S), Q3.1 (S), Q3.2 (S), Q3.3 (S), Q4.1 (S), Q4.2 (S), Q4.3 (S), R17.2, R18.2, R26.2, R27.2; also elsewhere on the board
GPIO1_MPU: J12.3; also elsewhere on the board
GPIO2_MPU: J12.5; also elsewhere on the board
GPIO3_MPU: J12.7; also elsewhere on the board
GPIO4_MPU: J12.9; also elsewhere on the board
GPIO5_MPU: J12.11; also elsewhere on the board
GPIO6_MPU: J12.13; also elsewhere on the board
GPIO7_MPU: J12.4; also elsewhere on the board
GPIO8_MPU: J12.6; also elsewhere on the board
GPIO9_MPU: J12.8; also elsewhere on the board
GPIO10_MPU: J12.10; also elsewhere on the board
GPIO11_MPU: J12.12; also elsewhere on the board
GPIO12_MPU: J12.14; also elsewhere on the board
I2C1_SCL_MPU: R22.1; also elsewhere on the board
I2C1_SCL_NAV: R22.2; also elsewhere on the board
I2C1_SDA_MPU: R23.1; also elsewhere on the board
I2C1_SDA_NAV: R23.2; also elsewhere on the board
I2C2_SCL_MPU: IC1.26 (SCL); also elsewhere on the board
I2C2_SDA_MPU: IC1.27 (SDA); also elsewhere on the board
IN-: J3.2, J4.2, J5.2, J6.2, J13.2, J13.4, J13.6, J13.8, J13.10, J13.12, J13.14, J13.16; also elsewhere on the board
INT1_MPU: R28.1; also elsewhere on the board
INT1_NAV: R28.2; also elsewhere on the board
INT2_MPU: R29.2; also elsewhere on the board
INT2_NAV: R29.1; also elsewhere on the board
unnamed: IC2.7 (~HOLD_(IO3_)), R31.1
unnamed: IC2.3 (~WP_(IO2_)), R30.1
unnamed: Q1.4 (G), R12.1, R17.1
unnamed: Q2.4 (G), R13.1, R18.1
unnamed: Q3.4 (G), R24.1, R26.1
unnamed: Q4.4 (G), R25.1, R27.1
PWM_00: IC1.6 (LED0), J20.1
PWM_01: IC1.7 (LED1), J20.2
PWM_02: IC1.8 (LED2), J20.3
PWM_03: IC1.9 (LED3), J20.4
PWM_04: IC1.10 (LED4), J20.5
PWM_05: IC1.11 (LED5), J20.6
PWM_06: IC1.12 (LED6), J20.7
PWM_07: IC1.13 (LED7), J20.8
Pyro_1_MPU: R12.2; also elsewhere on the board
Pyro_2_MPU: R13.2; also elsewhere on the board
Pyro_3_MPU: R24.2; also elsewhere on the board
Pyro_4_MPU: R25.2; also elsewhere on the board
SD_CLK_MPU: J7.5 (CLK); also elsewhere on the board
SD_CMD_MPU: J7.3 (CMD), R19.2; also elsewhere on the board
SD_DAT0_MPU: J7.7 (DAT0), R20.2; also elsewhere on the board
SD_DAT1_MPU: J7.8 (DAT1), R21.2; also elsewhere on the board
SD_DAT2_MPU: J7.1 (DAT2), R11.2; also elsewhere on the board
SD_DAT3_MPU: J7.2 (DAT3/CD), R16.2; also elsewhere on the board
SD_DET_MPU: J7.10 (DET_A); also elsewhere on the board
SPI1_CS_MPU: IC2.1 (~CS); also elsewhere on the board
SPI1_MISO_MPU: IC2.2 (DO_(IO1_)); also elsewhere on the board
SPI1_MOSI_MPU: IC2.5 (DI_(IO0_)); also elsewhere on the board
SPI1_SCK_MPU: IC2.6 (CLK); also elsewhere on the board
SPI4_MISO_MPU: J10.2; also elsewhere on the board
SPI4_MOSI_MPU: J10.3; also elsewhere on the board
SPI4_NSS_MPU: J10.5; also elsewhere on the board
SPI4_SCK_MPU: J10.4; also elsewhere on the board
USART1_RX_MPU: R15.2; also elsewhere on the board
USART1_RX_NAV: R14.2; also elsewhere on the board
USART1_TX_MPU: R14.1; also elsewhere on the board
USART1_TX_NAV: R15.1; also elsewhere on the board
USART2_RX_MPU: J9.2; also elsewhere on the board
USART2_TX_MPU: J9.3; also elsewhere on the board
USART3_RX_MPU: J8.2; also elsewhere on the board
USART3_TX_MPU: J8.3; also elsewhere on the board

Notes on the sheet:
I2C ADDRESS: 0x41
GPIO HEADER MPU
INT CONNECTION
UART CONNECTOR JST-GH 4-pol
Mircor SD Card Connector
SPI CONNECTOR JST-GH 6-pol
I2C Adress: 0x41 1000 001
PWM DRIVER FOR THE SERVOS
Flash
Pyro Channels
SERVO CONNECTORS HX PZ2.54-3x8P ZZ
UART CONNECTION
I2C1 CONNECTION

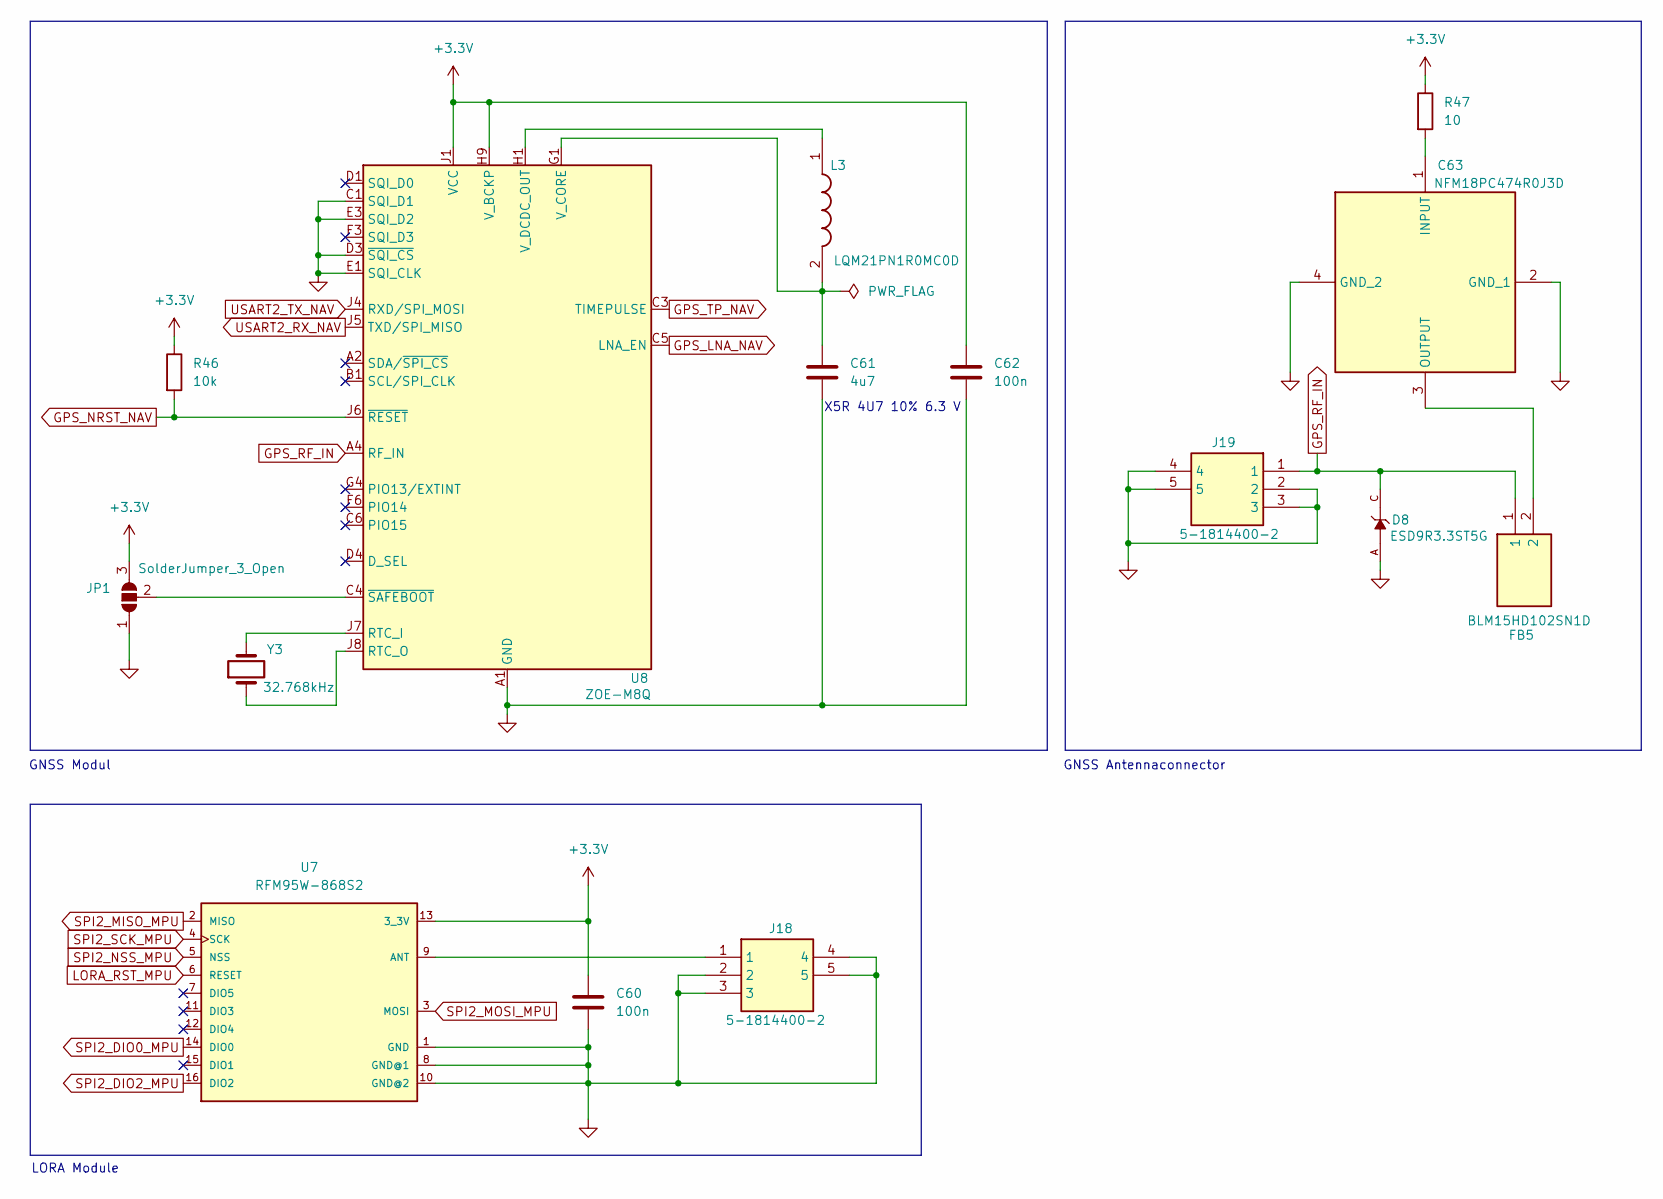
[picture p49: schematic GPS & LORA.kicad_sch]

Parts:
C60, C62: 100n; C_0402_1005Metric; LCSC C1525
C61: 4u7; CAPC2012X135N; LCSC C1746
C63: NFM18PC474R0J3D; Mouser Part Number 81-NFM18PC474R0J3D
D8: ESD9R3.3ST5G; SODFL1006X40N; PARTREV 2; LCSC C233388
FB5: BLM15HD102SN1D; NFZ15SG152SN10B; Mouser Part Number 81-BLM15HD102SN1D
J18, J19: 5-1814400-2; 518144002; Mouser Part Number 571-5-1814400-2
JP1: SolderJumper_3_Open; SolderJumper-3_P1.3mm_Open_RoundedPad1.0x1.5mm_NumberLabels
L3: LQM21PN1R0MC0D; Mouser Part Number 81-LQM21PN1R0MC0D
R46: 10k; R_0402_1005Metric; LCSC C25744
R47: 10; R_0402_1005Metric; LCSC C25077
U7: RFM95W-868S2; XCVR_RFM95W-868S2
U8: ZOE-M8Q; ublox_ZOE_M8; LCSC C7398634
Y3: 32.768kHz; Crystal_SMD_MicroCrystal_CC7V-T1A-2Pin_3.2x1.5mm; LCSC C7462182

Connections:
+3.3V: C60.1, C62.1, JP1.3 (B), R46.1, R47.1, U7.13 (3_3V), U8.H9 (V_BCKP), U8.J1 (VCC), U8.J2 (VCC); also elsewhere on the board
GND: C60.2, C61.2, C62.2, C63.2 (GND_1), C63.4 (GND_2), D8.A, J18.2, J18.3, J18.4, J18.5, J19.2, J19.3, J19.4, J19.5, JP1.1 (A), U7.1 (GND), U7.8 (GND@1), U7.10 (GND@2), U8.A1 (GND), U8.A3 (GND), U8.A5 (GND), U8.A7 (GND), U8.A8 (GND), U8.A9 (GND), U8.B9 (GND), U8.C1 (SQI_D1), U8.C7 (GND), U8.C9 (GND), U8.D3 (~SQI_CS), U8.D6 (GND), U8.D9 (GND), U8.E1 (SQI_CLK), U8.E3 (SQI_D2), U8.E7 (GND), U8.F7 (GND), U8.G3 (GND), U8.G6 (GND), U8.G7 (GND), U8.J3 (GND), U8.J9 (GND); also elsewhere on the board
GPS_LNA_NAV: U8.C5 (LNA_EN); also elsewhere on the board
GPS_NRST_NAV: R46.2, U8.J6 (~RESET)
GPS_RF_IN: D8.C, FB5.1, J19.1, U8.A4 (RF_IN)
GPS_TP_NAV: U8.C3 (TIMEPULSE); also elsewhere on the board
LORA_RST_MPU: U7.6 (RESET); also elsewhere on the board
unnamed: C63.1 (INPUT), R47.2
unnamed: C63.3 (OUTPUT), FB5.2
unnamed: JP1.2 (B), U8.C4 (~SAFEBOOT)
unnamed: J18.1, U7.9 (ANT)
unnamed: U8.J7 (RTC_I), Y3.2
unnamed: U8.J8 (RTC_O), Y3.1
unnamed: C61.1, L3.2, U8.G1 (V_CORE)
unnamed: L3.1, U8.H1 (V_DCDC_OUT)
SPI2_DIO0_MPU: U7.14 (DIO0); also elsewhere on the board
SPI2_DIO2_MPU: U7.16 (DIO2); also elsewhere on the board
SPI2_MISO_MPU: U7.2 (MISO); also elsewhere on the board
SPI2_MOSI_MPU: U7.3 (MOSI); also elsewhere on the board
SPI2_NSS_MPU: U7.5 (NSS); also elsewhere on the board
SPI2_SCK_MPU: U7.4 (SCK); also elsewhere on the board
USART2_RX_NAV: U8.J5 (TXD/SPI_MISO); also elsewhere on the board
USART2_TX_NAV: U8.J4 (RXD/SPI_MOSI); also elsewhere on the board

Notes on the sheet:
GNSS Antennaconnector
GNSS Modul
LORA Module
X5R 4U7 10% 6.3 V

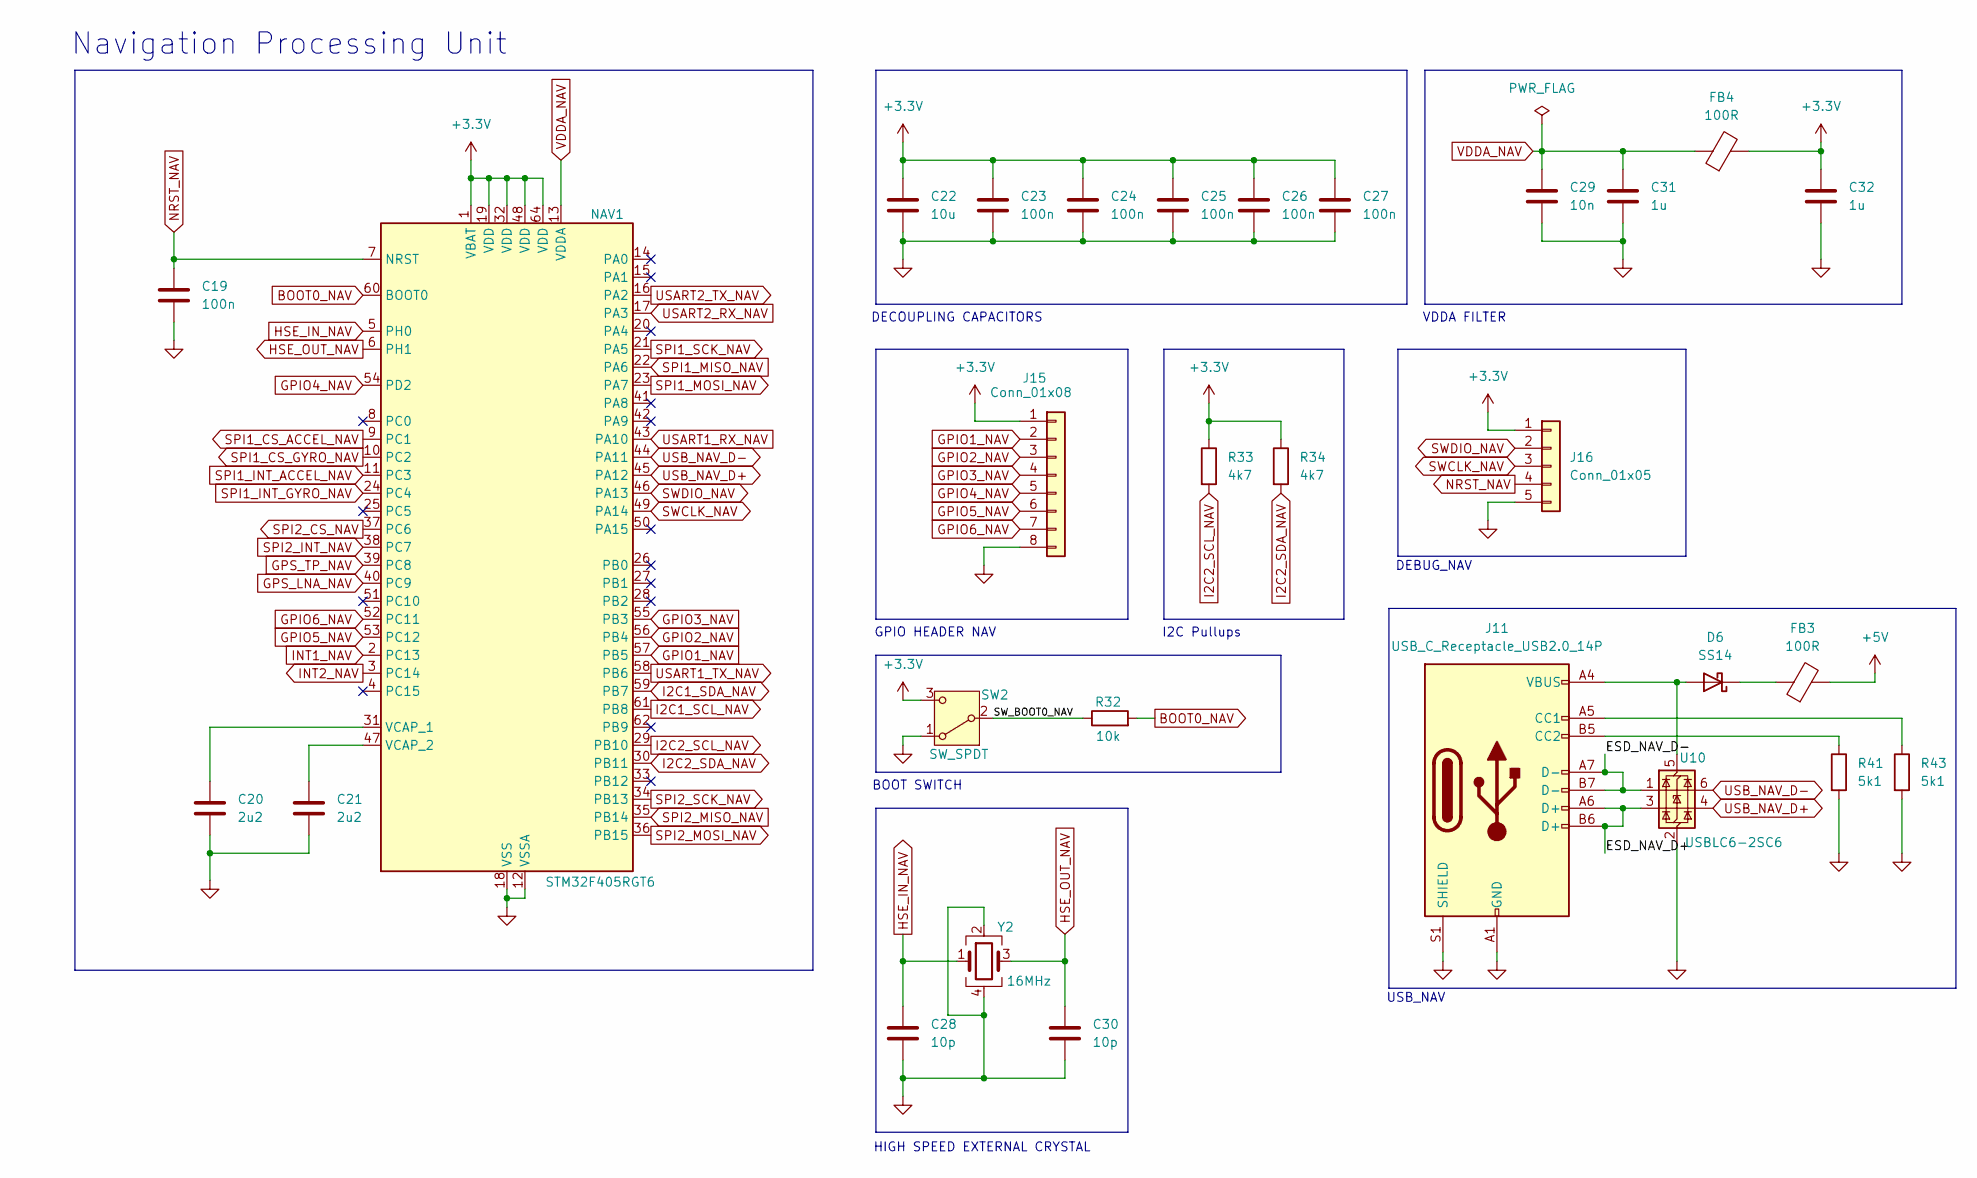
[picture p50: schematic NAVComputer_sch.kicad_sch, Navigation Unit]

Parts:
C19, C23, C24, C25, C26, C27: 100n; C_0402_1005Metric; LCSC C1525
C20, C21: 2u2; C_0805_2012Metric; LCSC C377773
C22: 10u; C_0805_2012Metric; LCSC C15850
C28, C30: 10p; C_0402_1005Metric; LCSC C32949
C29: 10n; C_0402_1005Metric; LCSC C15195
C31, C32: 1u; C_0805_2012Metric; LCSC C28323
D6: SS14; D_SMA; LCSC C2480
FB3, FB4: 100R; L_0805_2012Metric; LCSC C15957
J11: USB_C_Receptacle_USB2.0_14P; USB_C_Receptacle_HRO_TYPE-C-31-M-12; LCSC C165948
J15: Conn_01x08; PinHeader_1x08_P2.54mm_Vertical
J16: Conn_01x05; PinHeader_1x05_P2.54mm_Vertical
NAV1: STM32F405RGT6; LQFP-64_10x10mm_P0.5mm; LCSC C15742
R32: 10k; R_0402_1005Metric; LCSC C25744
R33, R34: 4k7; R_0402_1005Metric; LCSC C25900
R41, R43: 5k1; R_0402_1005Metric; LCSC C25905
SW2: SW_SPDT; SW_SPDT_PCM12; LCSC C221841
U10: USBLC6-2SC6; SOT-23-6; LCSC C7519
Y2: 16MHz; Crystal_SMD_3225-4Pin_3.2x2.5mm; LCSC C13738

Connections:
+3.3V: C22.1, C23.1, C24.1, C25.1, C26.1, C27.1, C32.1, FB4.2, J15.1, J16.1, NAV1.1 (VBAT), NAV1.19 (VDD), NAV1.32 (VDD), NAV1.48 (VDD), NAV1.64 (VDD), R33.1, R34.1, SW2.3 (C); also elsewhere on the board
+5V: FB3.2; also elsewhere on the board
/NAV/ESD_NAV_D+: J11.A6 (D+), J11.B6 (D+), U10.3 (I/O2)
/NAV/ESD_NAV_D-: J11.A7 (D-), J11.B7 (D-), U10.1 (I/O1)
/NAV/SW_BOOT0_NAV: R32.1, SW2.2 (B)
BOOT0_NAV: NAV1.60 (BOOT0), R32.2
GND: C19.2, C20.2, C21.2, C22.2, C23.2, C24.2, C25.2, C26.2, C27.2, C28.2, C29.2, C30.2, C31.2, C32.2, J11.A1 (GND), J11.A12 (GND), J11.B1 (GND), J11.B12 (GND), J11.S1 (SHIELD), J15.8, J16.5, NAV1.12 (VSSA), NAV1.18 (VSS), NAV1.63 (VSS), R41.2, R43.2, SW2.1 (A), U10.2 (GND), Y2.2, Y2.4; also elsewhere on the board
GPIO1_NAV: J15.2, NAV1.57 (PB5)
GPIO2_NAV: J15.3, NAV1.56 (PB4)
GPIO3_NAV: J15.4, NAV1.55 (PB3)
GPIO4_NAV: J15.5, NAV1.54 (PD2)
GPIO5_NAV: J15.6, NAV1.53 (PC12)
GPIO6_NAV: J15.7, NAV1.52 (PC11)
GPS_LNA_NAV: NAV1.40 (PC9); also elsewhere on the board
GPS_TP_NAV: NAV1.39 (PC8); also elsewhere on the board
HSE_IN_NAV: C28.1, NAV1.5 (PH0), Y2.1
HSE_OUT_NAV: C30.1, NAV1.6 (PH1), Y2.3
I2C1_SCL_NAV: NAV1.61 (PB8); also elsewhere on the board
I2C1_SDA_NAV: NAV1.59 (PB7); also elsewhere on the board
I2C2_SCL_NAV: NAV1.29 (PB10), R33.2; also elsewhere on the board
I2C2_SDA_NAV: NAV1.30 (PB11), R34.2; also elsewhere on the board
INT1_NAV: NAV1.2 (PC13); also elsewhere on the board
INT2_NAV: NAV1.3 (PC14); also elsewhere on the board
NRST_NAV: C19.1, J16.4, NAV1.7 (NRST)
unnamed: D6.2 (A), J11.A4 (VBUS), J11.A9 (VBUS), J11.B4 (VBUS), J11.B9 (VBUS), U10.5 (VBUS)
unnamed: D6.1 (K), FB3.1
unnamed: J11.A5 (CC1), R43.1
unnamed: J11.B5 (CC2), R41.1
unnamed: C20.1, NAV1.31 (VCAP_1)
unnamed: C21.1, NAV1.47 (VCAP_2)
SPI1_CS_ACCEL_NAV: NAV1.9 (PC1); also elsewhere on the board
SPI1_CS_GYRO_NAV: NAV1.10 (PC2); also elsewhere on the board
SPI1_INT_ACCEL_NAV: NAV1.11 (PC3); also elsewhere on the board
SPI1_INT_GYRO_NAV: NAV1.24 (PC4); also elsewhere on the board
SPI1_MISO_NAV: NAV1.22 (PA6); also elsewhere on the board
SPI1_MOSI_NAV: NAV1.23 (PA7); also elsewhere on the board
SPI1_SCK_NAV: NAV1.21 (PA5); also elsewhere on the board
SPI2_CS_NAV: NAV1.37 (PC6); also elsewhere on the board
SPI2_INT_NAV: NAV1.38 (PC7); also elsewhere on the board
SPI2_MISO_NAV: NAV1.35 (PB14); also elsewhere on the board
SPI2_MOSI_NAV: NAV1.36 (PB15); also elsewhere on the board
SPI2_SCK_NAV: NAV1.34 (PB13); also elsewhere on the board
SWCLK_NAV: J16.3, NAV1.49 (PA14)
SWDIO_NAV: J16.2, NAV1.46 (PA13)
USART1_RX_NAV: NAV1.43 (PA10); also elsewhere on the board
USART1_TX_NAV: NAV1.58 (PB6); also elsewhere on the board
USART2_RX_NAV: NAV1.17 (PA3); also elsewhere on the board
USART2_TX_NAV: NAV1.16 (PA2); also elsewhere on the board
USB_NAV_D+: NAV1.45 (PA12), U10.4 (I/O2)
USB_NAV_D-: NAV1.44 (PA11), U10.6 (I/O1)
VDDA_NAV: C29.1, C31.1, FB4.1, NAV1.13 (VDDA)

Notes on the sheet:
BOOT SWITCH
I2C Pullups
USB_NAV
Navigation Processing Unit
VDDA FILTER
GPIO HEADER NAV
DECOUPLING CAPACITORS
HIGH SPEED EXTERNAL CRYSTAL
DEBUG_NAV

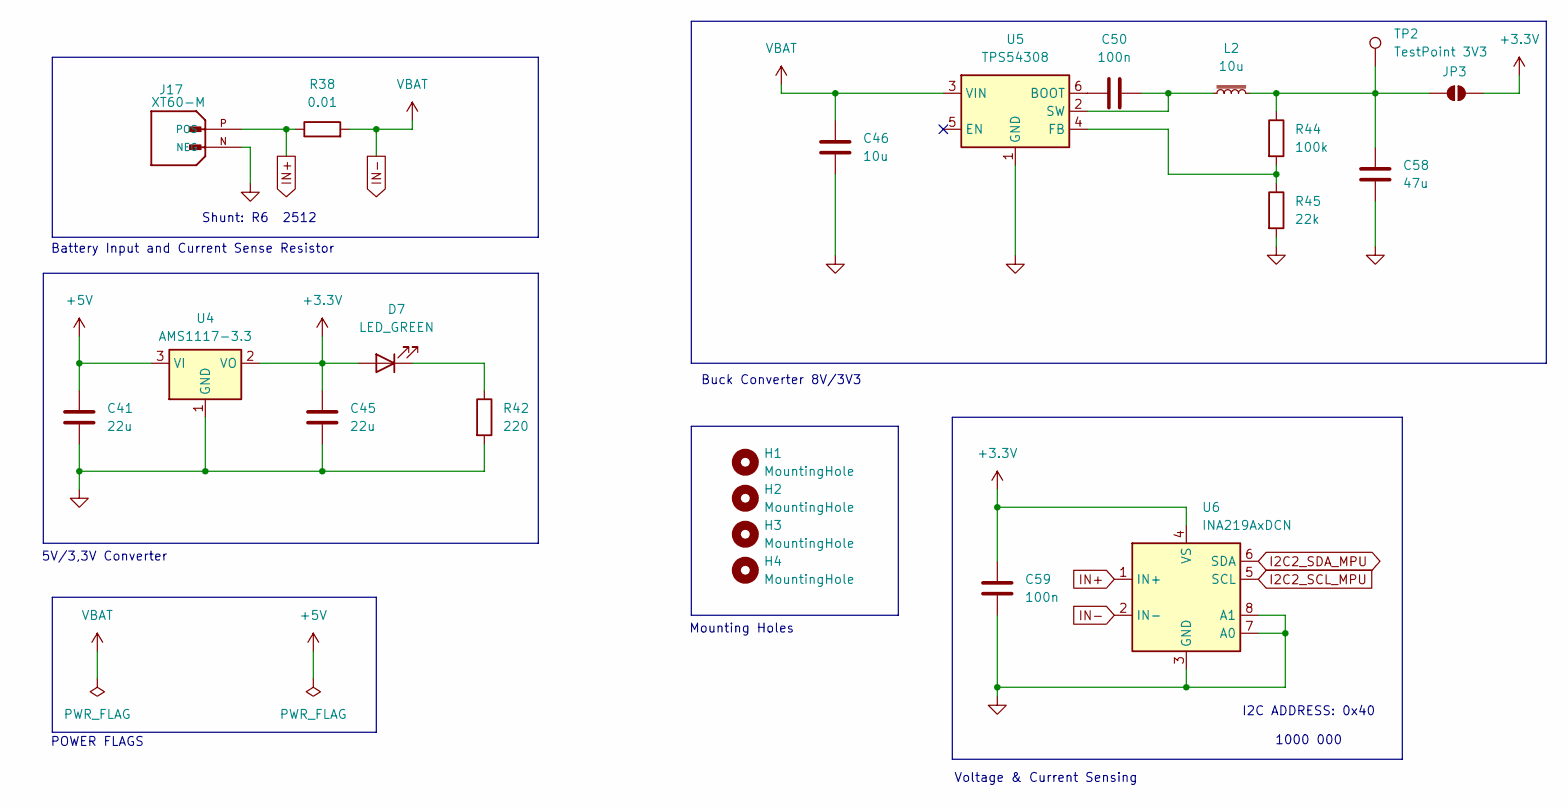
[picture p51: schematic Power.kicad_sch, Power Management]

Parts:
C41, C45: 22u; C_0805_2012Metric; LCSC C45783
C46: 10u; CAPC3225X270N; LCSC C380537
C50, C59: 100n; C_0402_1005Metric; LCSC C1525
C58: 47u; CAPC3225X270N; LCSC C77101
D7: LED_GREEN; LED_0603_1608Metric
H1, H2, H3, H4: MountingHole; MountingHole_3.2mm_M3
J17: XT60-M; AMASS_XT60-M; PARTREV V1.2; LCSC C98733
JP3: SolderJumper_2_Open; SolderJumper-2_P1.3mm_Open_RoundedPad1.0x1.5mm
L2: 10u; XAL5050822MEC; LCSC C5309356
R38: 0.01; R_2512_6332Metric; LCSC C316229
R42: 220; R_0402_1005Metric; LCSC C25091
R44: 100k; R_0402_1005Metric; LCSC C25741
R45: 22k; R_0402_1005Metric; LCSC C25768
TP2: TestPoint 3V3; TestPoint_Pad_D2.5mm
U4: AMS1117-3.3; SOT-223-3_TabPin2; LCSC C6186
U5: TPS54308; SOT-23-6; LCSC C168839
U6: INA219AxDCN; SOT-23-8; LCSC C87469

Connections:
+3.3V: C45.1, C59.1, D7.2 (A), JP3.2 (B), U4.2 (VO), U6.4 (VS); also elsewhere on the board
+5V: C41.1, U4.3 (VI); also elsewhere on the board
/Power Management/PWR LED Kathode: D7.1 (K), R42.1
GND: C41.2, C45.2, C46.2, C58.2, C59.2, J17.N (NEG), R42.2, R45.2, U4.1 (GND), U5.1 (GND), U6.3 (GND), U6.7 (A0), U6.8 (A1); also elsewhere on the board
I2C2_SCL_MPU: U6.5 (SCL); also elsewhere on the board
I2C2_SDA_MPU: U6.6 (SDA); also elsewhere on the board
IN+: J17.P (POS), R38.1, U6.1 (IN+)
IN-: C46.1, R38.2, U5.3 (VIN), U6.2 (IN-); also elsewhere on the board
unnamed: C58.1, JP3.1 (A), L2.2, R44.1, TP2.1
unnamed: C50.1, U5.6 (BOOT)
unnamed: R44.2, R45.1, U5.4 (FB)
unnamed: C50.2, L2.1, U5.2 (SW)

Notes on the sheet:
Mounting Holes
POWER FLAGS
5V/3,3V Converter
Battery Input and Current Sense Resistor
Buck Converter 8V/3V3
I2C ADDRESS: 0x40 1000 000
Voltage & Current Sensing
Shunt: R6 2512

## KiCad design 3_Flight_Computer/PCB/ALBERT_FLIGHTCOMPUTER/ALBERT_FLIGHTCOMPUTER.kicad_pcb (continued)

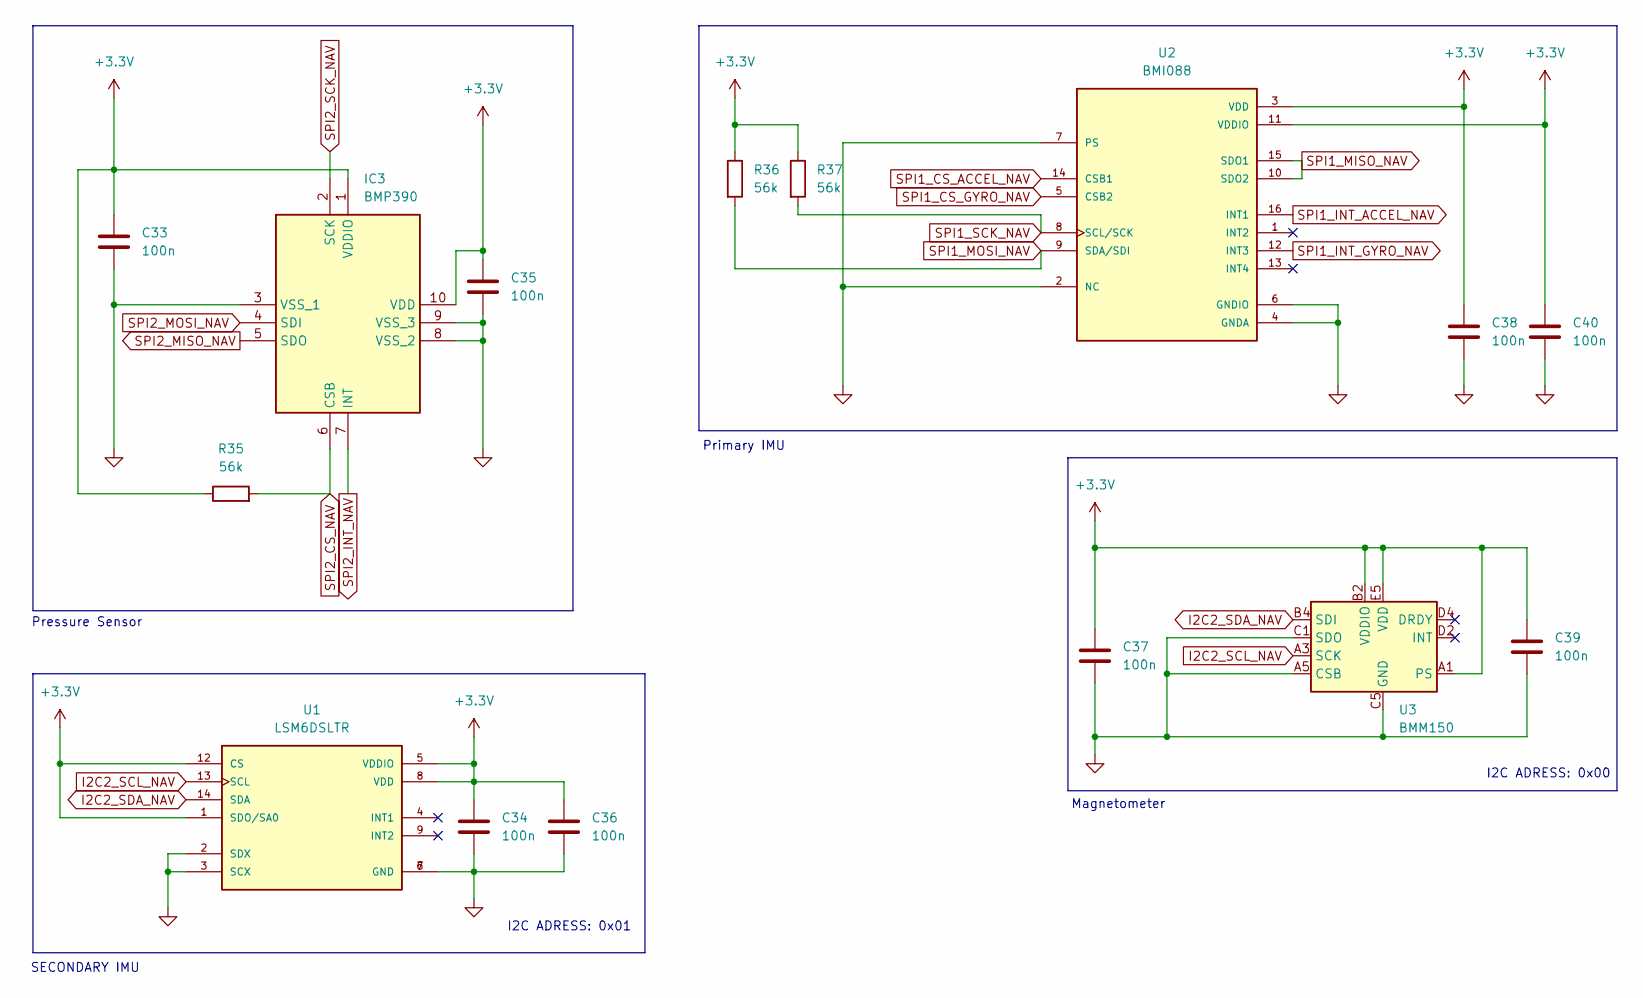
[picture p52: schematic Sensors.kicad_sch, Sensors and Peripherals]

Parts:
C33, C34, C35, C36, C37, C38, C39, C40: 100n; C_0402_1005Metric; LCSC C1525
IC3: BMP390; Mouser Part Number 262-BMP390
R35, R36, R37: 56k; R_0402_1005Metric; LCSC C25796
U1: LSM6DSLTR; PQFN50P300X250X86-14N; PARTREV 7; LCSC C126672
U2: BMI088; PQFN50P450X300X100-16N; LCSC C194919
U3: BMM150; WLCSP-12_1.56x1.56mm_P0.4mm; LCSC C171681

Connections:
+3.3V: C33.1, C34.1, C35.1, C36.1, C37.1, C38.1, C39.1, C40.1, IC3.1 (VDDIO), IC3.10 (VDD), R35.1, R36.1, R37.1, U1.1 (SDO/SA0), U1.5 (VDDIO), U1.8 (VDD), U1.12 (CS), U2.3 (VDD), U2.11 (VDDIO), U3.A1 (PS), U3.B2 (VDDIO), U3.E5 (VDD); also elsewhere on the board
GND: C33.2, C34.2, C35.2, C36.2, C37.2, C38.2, C39.2, C40.2, IC3.3 (VSS_1), IC3.8 (VSS_2), IC3.9 (VSS_3), U1.2 (SDX), U1.3 (SCX), U1.6 (GND), U1.7 (GND), U2.2 (NC), U2.4 (GNDA), U2.6 (GNDIO), U2.7 (PS), U3.A5 (CSB), U3.C1 (SDO), U3.C5 (GND), U3.E1 (GND), U3.E3 (GND); also elsewhere on the board
I2C2_SCL_NAV: U1.13 (SCL), U3.A3 (SCK); also elsewhere on the board
I2C2_SDA_NAV: U1.14 (SDA), U3.B4 (SDI); also elsewhere on the board
SPI1_CS_ACCEL_NAV: U2.14 (CSB1); also elsewhere on the board
SPI1_CS_GYRO_NAV: U2.5 (CSB2); also elsewhere on the board
SPI1_INT_ACCEL_NAV: U2.16 (INT1); also elsewhere on the board
SPI1_INT_GYRO_NAV: U2.12 (INT3); also elsewhere on the board
SPI1_MISO_NAV: U2.10 (SDO2), U2.15 (SDO1); also elsewhere on the board
SPI1_MOSI_NAV: R36.2, U2.9 (SDA/SDI); also elsewhere on the board
SPI1_SCK_NAV: R37.2, U2.8 (SCL/SCK); also elsewhere on the board
SPI2_CS_NAV: IC3.6 (CSB), R35.2; also elsewhere on the board
SPI2_INT_NAV: IC3.7 (INT); also elsewhere on the board
SPI2_MISO_NAV: IC3.5 (SDO); also elsewhere on the board
SPI2_MOSI_NAV: IC3.4 (SDI); also elsewhere on the board
SPI2_SCK_NAV: IC3.2 (SCK); also elsewhere on the board

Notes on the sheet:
Primary IMU
I2C ADRESS: 0x01
I2C ADRESS: 0x00
Magnetometer
Pressure Sensor
SECONDARY IMU

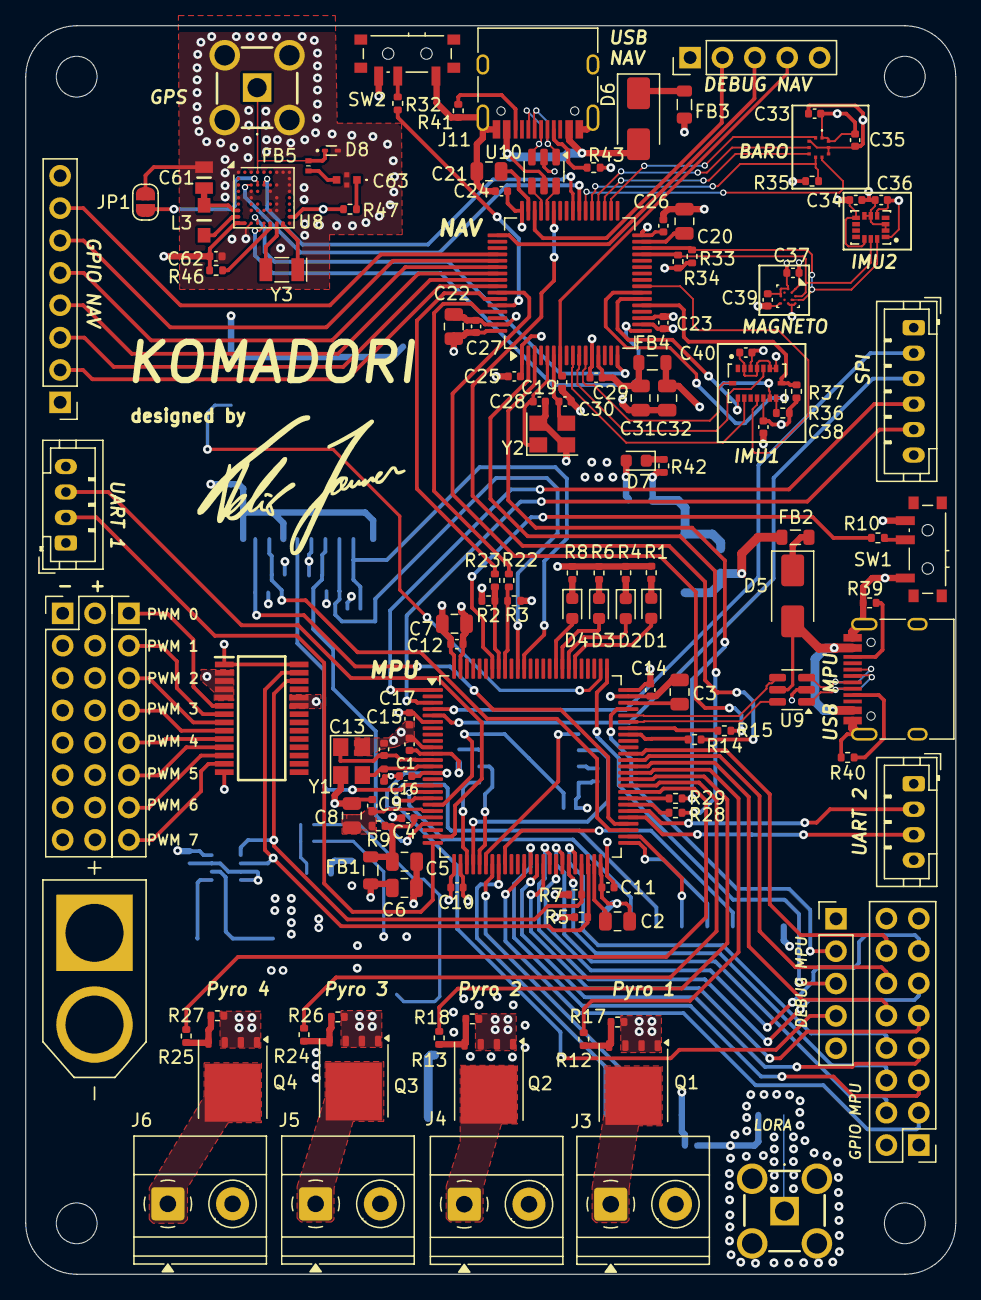
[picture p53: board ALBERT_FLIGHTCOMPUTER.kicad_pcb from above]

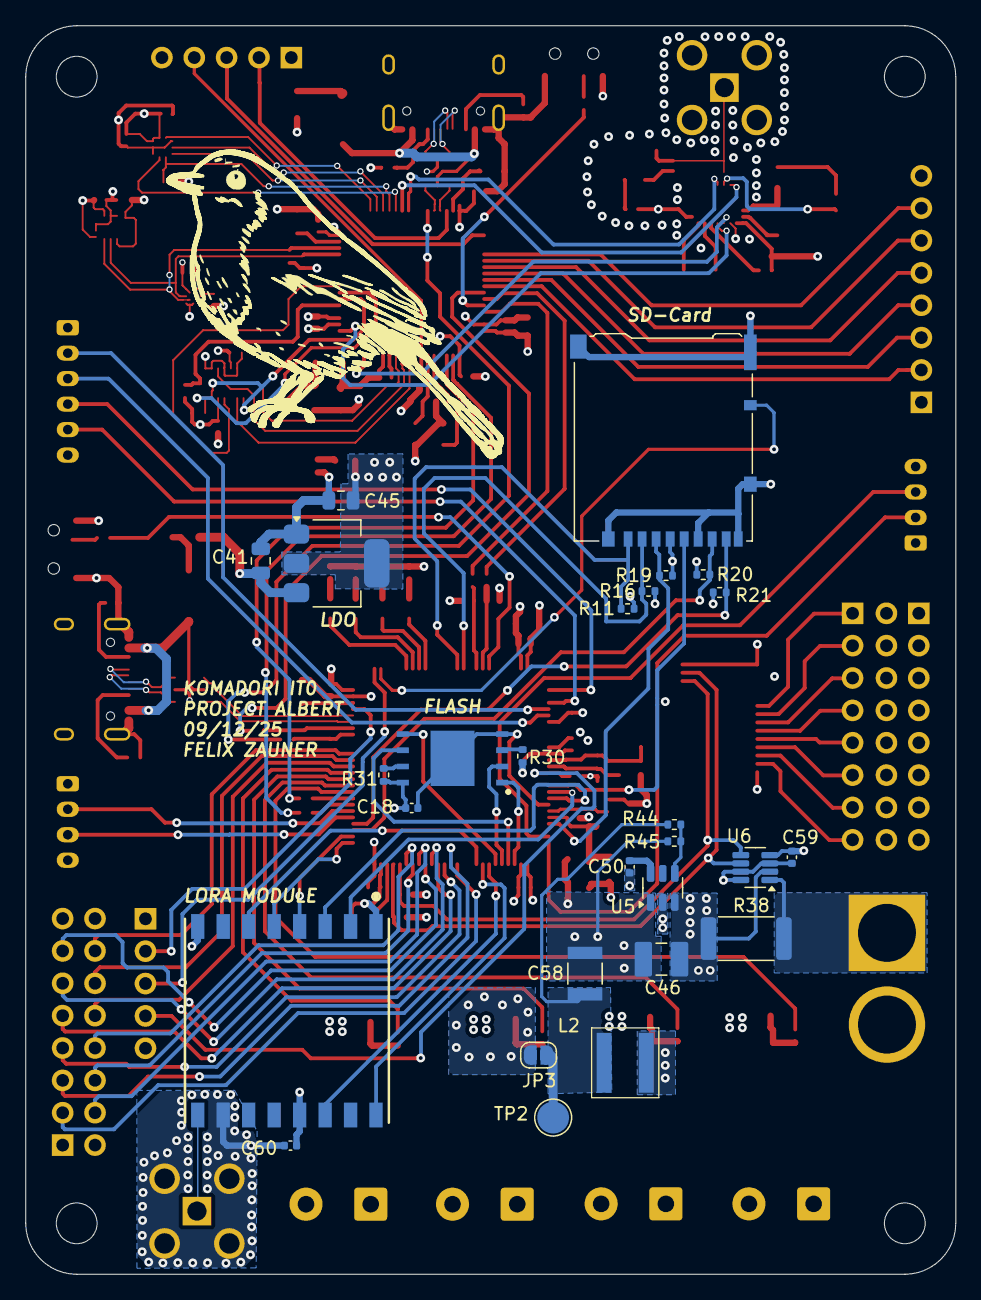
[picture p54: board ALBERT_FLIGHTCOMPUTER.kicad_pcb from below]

Board: 4 copper layers, 73.0 x 98.0 mm, 162 parts (27 on the bottom side), 163 nets.

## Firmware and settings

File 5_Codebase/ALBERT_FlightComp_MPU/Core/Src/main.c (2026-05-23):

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
/* Includes ------------------------------------------------------------------*/
#include "main.h"
#include "usb_device.h"

/* USER CODE BEGIN Includes */

#include "PCA9685.h"

#include "W25X0XGV.h"

#include "rfm95.h"

#include "usbd_cdc_if.h"
#include <stdio.h>
/* USER CODE END Includes */

/* USER CODE BEGIN PTD */

/* ============================================================
 *  Inter-chip protocol — NAV → MPU state packet.
 *  This struct MUST be byte-identical to the NAV side.
 *  See ALBERT_FlightComp/Core/Src/main.c for the canonical layout.
 * ============================================================ */
typedef struct __attribute__((packed)) {
    uint8_t  sync1;        /*  0   LINK_SYNC1          */
    uint8_t  sync2;        /*  1   LINK_SYNC2          */
    uint8_t  type;         /*  2   LINK_TYPE_STATE     */
    uint8_t  seq;          /*  3   rolling counter     */
    uint8_t  flags;        /*  4   bit0 = att_init, bit1 = mag_ref */
    uint8_t  reserved;     /*  5   keep total at 32    */
    float    phi;          /*  6   rad                 */
    float    theta;        /* 10   rad                 */
    float    psi;          /* 14   rad                 */
    float    p;            /* 18   rad/s (bias-corrected) */
    float    q;            /* 22                       */
    float    r;            /* 26                       */
    uint16_t crc;          /* 30   CRC-16/CCITT-FALSE  */
} link_state_t;
/* Compile-time size check (C89-portable; fails to compile with a
 * "negative size array" error if the struct is ever the wrong size). */
typedef char link_state_size_check[sizeof(link_state_t) == 32 ? 1 : -1];

/* USER CODE END PTD */

/* USER CODE BEGIN PD */

#define W25N01GV_STORAGE_PAGE_SIZ	W25X0XGV_MAX_COLUMN	// 2048 bytes per page

#define LINK_PACKET_LEN   32        /* must equal sizeof(link_state_t)        */
#define LINK_SYNC1        0xA1
#define LINK_SYNC2        0xB5
#define LINK_TYPE_STATE   0x01

#define LINK_FLAG_ATT_INIT   (1u << 0)
#define LINK_FLAG_MAG_REF    (1u << 1)

/* If no fresh state packet arrives within this many ms, the control law
 * should disengage and command neutral.  100 Hz nominal → 50 ms = miss
 * up to 5 packets before we consider the NAV silent. */
#define LINK_STATE_STALE_MS  50

#define USB_BUFLEN  160

/* USER CODE END PD */


I2C_HandleTypeDef hi2c1;
I2C_HandleTypeDef hi2c2;

RTC_HandleTypeDef hrtc;

SPI_HandleTypeDef hspi1;
SPI_HandleTypeDef hspi2;
SPI_HandleTypeDef hspi4;

UART_HandleTypeDef huart1;
UART_HandleTypeDef huart2;
UART_HandleTypeDef huart3;

/* USER CODE BEGIN PV */
PCA9685 servos;

/* =====================================================================
 *  Inter-chip UART link (MPU side)
 * =====================================================================
 *  MPU --INT1_MPU(out)--> INT1_NAV(EXTI rising) :  MPU is sending
 *  NAV --INT2_NAV(out)--> INT2_MPU(EXTI rising) :  NAV is sending
 *
 *  32-byte state packet (link_state_t).  Defined in PTD.
 * ===================================================================== */

uint8_t  link_rx_buf[LINK_PACKET_LEN];
volatile uint8_t nav_rx_ready  = 0;     /* set by HAL_UART_RxCpltCallback */
volatile uint8_t link_tx_busy  = 0;     /* gates mpu_send_packet re-entry */

/* Latest validated NAV → MPU state.  Updated by app_handle_link_rx()
 * after sync/CRC pass.  Read by app_run_control(). */
link_state_t  latest_state;
uint32_t      latest_state_ms     = 0;  /* HAL_GetTick() when populated   */
uint32_t      link_rx_pkts_ok     = 0;  /* good packets received          */
uint32_t      link_rx_pkts_drop   = 0;  /* sync or CRC failures           */
uint8_t       link_state_fresh    = 0;  /* set on every successful update */

/* USB telemetry buffer (mirror of NAV) */
uint8_t  usbTxBuf[USB_BUFLEN];
uint16_t usbTxBufLen;

/* USER CODE END PV */

void SystemClock_Config(void);
static void MPU_Config(void);
static void MX_GPIO_Init(void);
static void MX_I2C1_Init(void);
static void MX_I2C2_Init(void);
static void MX_USART1_UART_Init(void);
static void MX_SPI1_Init(void);
static void MX_SPI2_Init(void);
static void MX_USART2_UART_Init(void);
static void MX_SPI4_Init(void);
static void MX_USART3_UART_Init(void);
static void MX_RTC_Init(void);
/* USER CODE BEGIN PFP */

/* Main-loop helpers */
static void app_init_payload(void);
static void app_servo_show(void);
static void app_handle_link_rx(void);
static void app_run_control(void);
static void app_emit_telemetry(void);

/* Public TX entry — pulses INT1_MPU then starts a non-blocking UART TX */
HAL_StatusTypeDef mpu_send_packet(const uint8_t *buf, uint16_t n);

/* CRC-16/CCITT-FALSE (poly 0x1021, init 0xFFFF) */
static uint16_t crc16_ccitt(const uint8_t *data, uint16_t len);

/* USER CODE END PFP */

/* USER CODE BEGIN 0 */

uint8_t tx_buff[]={0,1,2,3,4,5,6,7,8,9};


/* ---------------------------------------------------------------------
 *  app_init_payload
 *  Brings up the servo driver, the on-board NAND flash, and (later)
 *  the RFM95 LoRa modem.  Kept separate from main() so the boot
 *  sequence is one line: app_init_payload().
 * ------------------------------------------------------------------ */
static void app_init_payload(void)
{
    /* PWM driver — neutral pulse on all four channels */
    PCA9685_Init(&servos, &hi2c2, 330);
    for (uint8_t ch = 0; ch < 4; ch++) PCA9685_SetMicros(&servos, ch, 0);
    HAL_Delay(1000);

    /* Arm motors (1500 µs centre + 500 µs idle on the others)         */
    PCA9685_SetMicros(&servos, 0, 1500);
    PCA9685_SetMicros(&servos, 1, 1500);
    PCA9685_SetMicros(&servos, 2, 1500);
    PCA9685_SetMicros(&servos, 3, 1500);
    HAL_Delay(1000);

    /* NAND flash — erase block holding page 0 so logging starts clean */
    W25X0XGV_begin();
    W25X0XGV_block_erase(0);

    /* Pyro 2 default state (kept from original boot sequence)         */
    HAL_GPIO_WritePin(Pyro_1_MPU_GPIO_Port, Pyro_1_MPU_Pin, GPIO_PIN_SET);
    HAL_GPIO_WritePin(Pyro_2_MPU_GPIO_Port, Pyro_2_MPU_Pin, GPIO_PIN_SET);
    HAL_GPIO_WritePin(Pyro_3_MPU_GPIO_Port, Pyro_3_MPU_Pin, GPIO_PIN_SET);
    HAL_GPIO_WritePin(Pyro_4_MPU_GPIO_Port, Pyro_4_MPU_Pin, GPIO_PIN_SET);

    /* RFM95 — disabled until the radio is on the to-do list.  The
     * struct is left visible to the rest of the file via PV section
     * if needed; nothing in the main loop depends on it today. */
}


/* ---------------------------------------------------------------------
 *  Servo helpers used by the boot-time self-test "show".
 *  Smooth ramps via small µs steps + short HAL_Delay slices so the
 *  fins move at a visible, deliberate rate (not a snap).
 * ------------------------------------------------------------------ */
static void servo_ramp_one(uint8_t ch, int from_us, int to_us)
{
    const int step = (to_us > from_us) ? 10 : -10;
    int us = from_us;
    while ((step > 0 && us <= to_us) || (step < 0 && us >= to_us)) {
        PCA9685_SetMicros(&servos, ch, (uint16_t)us);
        HAL_Delay(5);                 /* 50 steps × 5 ms = 250 ms per 500 µs leg */
        us += step;
    }
    PCA9685_SetMicros(&servos, ch, (uint16_t)to_us);
}

static void servo_ramp_pair(uint8_t ch_pos, uint8_t ch_neg,
                            int from_us, int to_us)
{
    /* ch_pos sweeps from_us → to_us;  ch_neg mirrors about 1500 µs. */
    const int step = (to_us > from_us) ? 10 : -10;
    int us = from_us;
    while ((step > 0 && us <= to_us) || (step < 0 && us >= to_us)) {
        PCA9685_SetMicros(&servos, ch_pos, (uint16_t)us);
        PCA9685_SetMicros(&servos, ch_neg, (uint16_t)(3000 - us)); /* mirror */
        HAL_Delay(5);
        us += step;
    }
    PCA9685_SetMicros(&servos, ch_pos, (uint16_t)to_us);
    PCA9685_SetMicros(&servos, ch_neg, (uint16_t)(3000 - to_us));
}

static void servos_all_neutral(void)
{
    for (uint8_t ch = 0; ch < 4; ch++)
        PCA9685_SetMicros(&servos, ch, 1500);
}


/* ---------------------------------------------------------------------
 *  app_servo_show
 *  One-shot boot-time fin exercise.  Roughly 12 seconds total.
 *
 *    Act 1  (≈6 s) — each channel ramps neutral → max → min → neutral,
 *                    in turn.  Visual confirmation of wiring per fin.
 *    Act 2  (≈2 s) — pitch pair (0 ↑, 2 ↓) full sweep then back.
 *    Act 3  (≈2 s) — yaw   pair (1 ↑, 3 ↓) full sweep then back.
 *    Act 4  (≈2 s) — "wave": each fin in sequence flicks +max then back.
 *    Finale          — all four to neutral, brief hold.
 *
 *  Blocking by design.  Called once from main() before the loop starts.
 *  The NAV's INT2_MPU edges that arrive during the show will still
 *  rearm RX via the EXTI ISR, so no inbound packets are lost.
 * ------------------------------------------------------------------ */
static void app_servo_show(void)
{
    servos_all_neutral();
    HAL_Delay(500);

    /* ---- Act 1: each channel, alone ---------------------------------- */
    for (uint8_t ch = 0; ch < 4; ch++) {
        servo_ramp_one(ch, 1500, 2000);
        servo_ramp_one(ch, 2000, 1000);
        servo_ramp_one(ch, 1000, 1500);
        HAL_Delay(150);
    }

    /* ---- Act 2: pitch pair (mirrored) -------------------------------- */
    servo_ramp_pair(0, 2, 1500, 2000);
    servo_ramp_pair(0, 2, 2000, 1000);
    servo_ramp_pair(0, 2, 1000, 1500);
    HAL_Delay(250);

    /* ---- Act 3: yaw pair (mirrored) ---------------------------------- */
    servo_ramp_pair(1, 3, 1500, 2000);
    servo_ramp_pair(1, 3, 2000, 1000);
    servo_ramp_pair(1, 3, 1000, 1500);
    HAL_Delay(250);

    /* ---- Act 4: a quick "wave" round the cluster --------------------- */
    for (uint8_t ch = 0; ch < 4; ch++) {
        servo_ramp_one(ch, 1500, 1900);
        servo_ramp_one(ch, 1900, 1500);
    }

    /* ---- Finale: lock everything at neutral and hold ----------------- */
    servos_all_neutral();
    HAL_Delay(500);
}


/* ---------------------------------------------------------------------
 *  mpu_send_packet
 *  Pulses INT1_MPU and starts an interrupt-driven UART1 transmit.
 *  NAV's EXTI on INT1_NAV arms its RX before the first byte lands.
 * ------------------------------------------------------------------ */
HAL_StatusTypeDef mpu_send_packet(const uint8_t *buf, uint16_t n)
{
    if (link_tx_busy)                        return HAL_BUSY;
    if (n != LINK_PACKET_LEN || buf == NULL) return HAL_ERROR;

    link_tx_busy = 1;

    HAL_GPIO_WritePin(INT1_MPU_GPIO_Port, INT1_MPU_Pin, GPIO_PIN_SET);
    /* ~1 µs settle — ISR latency on NAV is well under one UART byte time */
    for (volatile int i = 0; i < 32; i++) __NOP();
    HAL_GPIO_WritePin(INT1_MPU_GPIO_Port, INT1_MPU_Pin, GPIO_PIN_RESET);

    /* HAL_UART_Transmit_IT takes a non-const pointer — cast away const.
     * Safe: HAL only reads from the buffer during the transfer. */
    HAL_StatusTypeDef st = HAL_UART_Transmit_IT(&huart1,
                                                (uint8_t *)buf, n);
    if (st != HAL_OK) link_tx_busy = 0;
    return st;
}


/* ---------------------------------------------------------------------
 *  CRC-16 / CCITT-FALSE  —  must match the NAV-side implementation.
 * ------------------------------------------------------------------ */
static uint16_t crc16_ccitt(const uint8_t *data, uint16_t len)
{
    uint16_t crc = 0xFFFF;
    while (len--) {
        crc ^= (uint16_t)(*data++) << 8;
        for (int i = 0; i < 8; i++)
            crc = (crc & 0x8000) ? (uint16_t)((crc << 1) ^ 0x1021)
                                 : (uint16_t)(crc << 1);
    }
    return crc;
}


/* ---------------------------------------------------------------------
 *  app_handle_link_rx
 *  Drain a completed NAV→MPU packet, validate sync + CRC, and copy
 *  the payload into latest_state.  A garbled packet bumps the drop
 *  counter; a valid one bumps the ok counter and refreshes the timer.
 * ------------------------------------------------------------------ */
static void app_handle_link_rx(void)
{
    if (!nav_rx_ready) return;
    nav_rx_ready = 0;

    /* Re-arm RX first so we never miss the next packet while parsing. */
    if (huart1.RxState == HAL_UART_STATE_READY) {
        HAL_UART_Receive_IT(&huart1, link_rx_buf, LINK_PACKET_LEN);
    }

    /* Sync check — cheap reject before the CRC math. */
    if (link_rx_buf[0] != LINK_SYNC1 ||
        link_rx_buf[1] != LINK_SYNC2 ||
        link_rx_buf[2] != LINK_TYPE_STATE)
    {
        link_rx_pkts_drop++;
        return;
    }

    /* CRC over everything except the trailing two CRC bytes themselves */
    const uint16_t crc_calc = crc16_ccitt(link_rx_buf, LINK_PACKET_LEN - 2);
    const uint16_t crc_rx   = (uint16_t)link_rx_buf[LINK_PACKET_LEN - 2]
                            | ((uint16_t)link_rx_buf[LINK_PACKET_LEN - 1] << 8);
    if (crc_calc != crc_rx) {
        link_rx_pkts_drop++;
        return;
    }

    /* Looks good — overlay the struct on the buffer. */
    const link_state_t *pkt = (const link_state_t *)link_rx_buf;
    latest_state      = *pkt;
    latest_state_ms   = HAL_GetTick();
    link_state_fresh  = 1;
    link_rx_pkts_ok++;
}


/* ---------------------------------------------------------------------
 *  Control-law gains and limits (tune on the bench, NOT in flight)
 *  --------------------------------------------------------------------
 *  Target: pitch (theta) and yaw (psi) both → 0.  Phi (roll about the
 *  long axis) is intentionally not controlled here — it's either left
 *  passively damped by the fins, or handled by a separate roll loop
 *  later (delta_r on differential fin deflection).
 *
 *  Sign convention (from RocketModel.c):
 *     Cm  = ... + Cm_delta * delta_eta   → δ_η ↑ pitches up   (θ↑)
 *     Cn  = ... + Cn_delta * delta_zeta  → δ_ζ ↑ yaws right   (ψ↑)
 *  So to bring θ back to 0 when θ>0, we need δ_η<0 → gain is negative. */
#define CTRL_KP_THETA          (-3.0f)   /* δ_η  per rad of θ  [rad/rad] */
#define CTRL_KP_PSI            (-3.0f)   /* δ_ζ  per rad of ψ  [rad/rad] */

/* Mechanical fin deflection limit, radians.  ±20° ≈ ±0.35 rad. */
#define CTRL_DELTA_MAX_RAD     (0.35f)

/* Servo mapping: 1500 µs = neutral.  500 µs ↔ CTRL_DELTA_MAX_RAD. */
#define CTRL_SERVO_NEUTRAL_US  (1500)
#define CTRL_SERVO_US_PER_RAD  (500.0f / CTRL_DELTA_MAX_RAD)   /* ≈1428 */
#define CTRL_SERVO_MIN_US      (1000)
#define CTRL_SERVO_MAX_US      (2000)


static inline float clampf(float v, float lo, float hi)
{
    return v < lo ? lo : (v > hi ? hi : v);
}

static inline uint16_t fin_us(float delta_rad)
{
    delta_rad = clampf(delta_rad, -CTRL_DELTA_MAX_RAD, CTRL_DELTA_MAX_RAD);
    float us = (float)CTRL_SERVO_NEUTRAL_US + delta_rad * CTRL_SERVO_US_PER_RAD;
    if (us < CTRL_SERVO_MIN_US) us = CTRL_SERVO_MIN_US;
    if (us > CTRL_SERVO_MAX_US) us = CTRL_SERVO_MAX_US;
    return (uint16_t)us;
}


/* ---------------------------------------------------------------------
 *  app_run_control
 *  Pitch + yaw P-controller.  Reads theta, psi from latest_state;
 *  drives the four fins via the PCA9685.  Disengages and commands
 *  neutral if the NAV link is stale or the EKF hasn't initialised.
 *
 *  Fin assignment (assumes "+" config — adjust signs if your fins
 *  are mounted in an "X" arrangement):
 *     channel 0 →  +δ_η   (pitch fin, top)
 *     channel 2 →  −δ_η   (pitch fin, bottom)
 *     channel 1 →  +δ_ζ   (yaw   fin, right)
 *     channel 3 →  −δ_ζ   (yaw   fin, left)
 * ------------------------------------------------------------------ */
static void app_run_control(void)
{
    const uint8_t link_alive =
        link_rx_pkts_ok > 0 &&
        (HAL_GetTick() - latest_state_ms) < LINK_STATE_STALE_MS;

    const uint8_t att_ready =
        (latest_state.flags & LINK_FLAG_ATT_INIT) != 0;

    if (!link_alive || !att_ready) {
        /* Failsafe — neutral pulse on all fin channels */
        PCA9685_SetMicros(&servos, 0, CTRL_SERVO_NEUTRAL_US);
        PCA9685_SetMicros(&servos, 1, CTRL_SERVO_NEUTRAL_US);
        PCA9685_SetMicros(&servos, 2, CTRL_SERVO_NEUTRAL_US);
        PCA9685_SetMicros(&servos, 3, CTRL_SERVO_NEUTRAL_US);
        return;
    }

    /* --- error: target attitude is θ = 0, ψ = 0 ---------------------- */
    const float err_theta = 0.0f - latest_state.theta;
    const float err_psi   = 0.0f - latest_state.psi;

    /* --- P-control on each angle ------------------------------------- */
    const float delta_eta  = CTRL_KP_THETA * err_theta;   /* pitch fin command */
    const float delta_zeta = CTRL_KP_PSI   * err_psi;     /* yaw   fin command */

    /* --- Map to four-fin "+" output (mirrored opposing pair) --------- */
    PCA9685_SetMicros(&servos, 0, fin_us(+delta_eta));
    PCA9685_SetMicros(&servos, 2, fin_us(-delta_eta));
    PCA9685_SetMicros(&servos, 1, fin_us(+delta_zeta));
    PCA9685_SetMicros(&servos, 3, fin_us(-delta_zeta));

    link_state_fresh = 0;   /* consumed */
}
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
int main(void)
{

  /* MPU Configuration--------------------------------------------------------*/
  MPU_Config();

  /* MCU Configuration--------------------------------------------------------*/

  /* Reset of all peripherals, Initializes the Flash interface and the Systick. */
  HAL_Init();

  /* Configure the system clock */
  SystemClock_Config();

  /* Initialize all configured peripherals */
  MX_GPIO_Init();
  MX_I2C1_Init();
  MX_I2C2_Init();
  MX_USART1_UART_Init();
  MX_SPI1_Init();
  MX_SPI2_Init();
  MX_USART2_UART_Init();
  MX_SPI4_Init();
  MX_USART3_UART_Init();
  MX_RTC_Init();
  MX_USB_DEVICE_Init();
  /* USER CODE BEGIN 2 */

  app_init_payload();        /* PCA9685 servos, NAND flash, Pyro defaults */
  app_servo_show();          /* ~12 s boot-time fin exercise               */

  /* Defensive initial RX arm — even before the very first INT2_MPU edge
   * the MPU is ready to catch a NAV-initiated packet. */
  HAL_UART_Receive_IT(&huart1, link_rx_buf, LINK_PACKET_LEN);

  /* USER CODE END 2 */

  /* Infinite loop */
  /* USER CODE BEGIN WHILE */
  while (1)
  {
      app_handle_link_rx();     /* validate + decode NAV→MPU state packet */
      app_run_control();        /* fin control law (placeholder)          */
      app_emit_telemetry();     /* 10 Hz USB telemetry: $MPU frame        */
    /* USER CODE END WHILE */

    /* USER CODE BEGIN 3 */
  }
  /* USER CODE END 3 */
}

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
/* USER CODE BEGIN 4 */

/* ---------------------------------------------------------------------
 *  HAL EXTI dispatcher — only handles INT2_MPU (the NAV→MPU "I'm
 *  sending" line).  Other EXTI sources on this board don't have any
 *  attached behaviour yet.
 * ------------------------------------------------------------------ */
void HAL_GPIO_EXTI_Callback(uint16_t GPIO_Pin)
{
    if (GPIO_Pin == INT2_MPU_Pin) {
        if (huart1.RxState == HAL_UART_STATE_READY) {
            HAL_UART_Receive_IT(&huart1, link_rx_buf, LINK_PACKET_LEN);
        }
    }
}


/* HAL UART completion callbacks — both raise main-loop flags only. */
void HAL_UART_RxCpltCallback(UART_HandleTypeDef *h)
{
    if (h->Instance == USART1) {
        nav_rx_ready = 1;
    }
}

void HAL_UART_TxCpltCallback(UART_HandleTypeDef *h)
{
    if (h->Instance == USART1) {
        link_tx_busy = 0;
    }
}


/* ---------------------------------------------------------------------
 *  EXTI15_10_IRQHandler — PD11 (INT2_MPU) sits on EXTI11.  The
 *  CubeMX-generated stm32h7xx_it.c does not contain a handler for it,
 *  so we define a strong override here and forward to the HAL.
 * ------------------------------------------------------------------ */
void EXTI15_10_IRQHandler(void)
{
    HAL_GPIO_EXTI_IRQHandler(INT2_MPU_Pin);
}


/* ---------------------------------------------------------------------
 *  USART1_IRQHandler — required for the HAL's _IT and _DMA UART paths.
 * ------------------------------------------------------------------ */
void USART1_IRQHandler(void)
{
    HAL_UART_IRQHandler(&huart1);
}

/* USER CODE END 4 */

 /* MPU Configuration */

void MPU_Config(void)
{
  MPU_Region_InitTypeDef MPU_InitStruct = {0};

  /* Disables the MPU */
  HAL_MPU_Disable();

  /** Initializes and configures the Region and the memory to be protected
  */
  MPU_InitStruct.Enable = MPU_REGION_ENABLE;
  MPU_InitStruct.Number = MPU_REGION_NUMBER0;
  MPU_InitStruct.BaseAddress = 0x0;
  MPU_InitStruct.Size = MPU_REGION_SIZE_4GB;
  MPU_InitStruct.SubRegionDisable = 0x87;
  MPU_InitStruct.TypeExtField = MPU_TEX_LEVEL0;
  MPU_InitStruct.AccessPermission = MPU_REGION_NO_ACCESS;
  MPU_InitStruct.DisableExec = MPU_INSTRUCTION_ACCESS_DISABLE;
  MPU_InitStruct.IsShareable = MPU_ACCESS_SHAREABLE;
  MPU_InitStruct.IsCacheable = MPU_ACCESS_NOT_CACHEABLE;
  MPU_InitStruct.IsBufferable = MPU_ACCESS_NOT_BUFFERABLE;

  HAL_MPU_ConfigRegion(&MPU_InitStruct);
  /* Enables the MPU */
  HAL_MPU_Enable(MPU_PRIVILEGED_DEFAULT);

}

/**
  * @brief  This function is executed in case of error occurrence.
  * @retval None
  */
void Error_Handler(void)
{
  /* USER CODE BEGIN Error_Handler_Debug */
  /* User can add his own implementation to report the HAL error return state */
  __disable_irq();
  while (1)
  {
  }
  /* USER CODE END Error_Handler_Debug */
}
#ifdef USE_FULL_ASSERT
/**
  * @brief  Reports the name of the source file and the source line number
  *         where the assert_param error has occurred.
  * @param  file: pointer to the source file name
  * @param  line: assert_param error line source number
  * @retval None
  */
void assert_failed(uint8_t *file, uint32_t line)
{
  /* USER CODE BEGIN 6 */
  /* User can add his own implementation to report the file name and line number,
     ex: printf("Wrong parameters value: file %s on line %d\r\n", file, line) */
  /* USER CODE END 6 */
}
#endif /* USE_FULL_ASSERT */

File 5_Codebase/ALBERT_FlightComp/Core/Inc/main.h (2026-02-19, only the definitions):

#define INT1_NAV_Pin GPIO_PIN_13
#define INT1_NAV_GPIO_Port GPIOC
#define INT2_NAV_Pin GPIO_PIN_14
#define INT2_NAV_GPIO_Port GPIOC
#define SPI1_CS_ACCEL_NAV_Pin GPIO_PIN_1
#define SPI1_CS_ACCEL_NAV_GPIO_Port GPIOC
#define SPI1_CS_GYRO_NAV_Pin GPIO_PIN_2
#define SPI1_CS_GYRO_NAV_GPIO_Port GPIOC
#define SPI1_INT_ACCEL_NAV_Pin GPIO_PIN_3
#define SPI1_INT_ACCEL_NAV_GPIO_Port GPIOC
#define SPI1_INT_ACCEL_NAV_EXTI_IRQn EXTI3_IRQn
#define USART2_TX_NAV_Pin GPIO_PIN_2
#define USART2_TX_NAV_GPIO_Port GPIOA
#define USART2_RX_NAV_Pin GPIO_PIN_3
#define USART2_RX_NAV_GPIO_Port GPIOA
#define SPI1_SCK_NAV_Pin GPIO_PIN_5
#define SPI1_SCK_NAV_GPIO_Port GPIOA
#define SPI1_MISO_NAV_Pin GPIO_PIN_6
#define SPI1_MISO_NAV_GPIO_Port GPIOA
#define SPI1_MOSI_NAV_Pin GPIO_PIN_7
#define SPI1_MOSI_NAV_GPIO_Port GPIOA
#define SPI1_INT_GYRO_NAV_Pin GPIO_PIN_4
#define SPI1_INT_GYRO_NAV_GPIO_Port GPIOC
#define SPI1_INT_GYRO_NAV_EXTI_IRQn EXTI4_IRQn
#define I2C2_SCL_NAV_Pin GPIO_PIN_10
#define I2C2_SCL_NAV_GPIO_Port GPIOB
#define I2C2_SDA_NAV_Pin GPIO_PIN_11
#define I2C2_SDA_NAV_GPIO_Port GPIOB
#define SPI2_SCK_NAV_Pin GPIO_PIN_13
#define SPI2_SCK_NAV_GPIO_Port GPIOB
#define SPI2_MISO_NAV_Pin GPIO_PIN_14
#define SPI2_MISO_NAV_GPIO_Port GPIOB
#define SPI2_MOSI_NAV_Pin GPIO_PIN_15
#define SPI2_MOSI_NAV_GPIO_Port GPIOB
#define SPI2_CS_NAV_Pin GPIO_PIN_6
#define SPI2_CS_NAV_GPIO_Port GPIOC
#define SPI2_INT_NAV_Pin GPIO_PIN_7
#define SPI2_INT_NAV_GPIO_Port GPIOC
#define SPI2_INT_NAV_EXTI_IRQn EXTI9_5_IRQn
#define GPS_TP_NAV_Pin GPIO_PIN_8
#define GPS_TP_NAV_GPIO_Port GPIOC
#define GPS_LNA_NAV_Pin GPIO_PIN_9
#define GPS_LNA_NAV_GPIO_Port GPIOC
#define USART1_RX_NAV_Pin GPIO_PIN_10
#define USART1_RX_NAV_GPIO_Port GPIOA
#define USB_D__NAV_Pin GPIO_PIN_11
#define USB_D__NAV_GPIO_Port GPIOA
#define USB_D__NAVA12_Pin GPIO_PIN_12
#define USB_D__NAVA12_GPIO_Port GPIOA
#define SWDIO_NAV_Pin GPIO_PIN_13
#define SWDIO_NAV_GPIO_Port GPIOA
#define SWCLK_NAV_Pin GPIO_PIN_14
#define SWCLK_NAV_GPIO_Port GPIOA
#define GPIO6_NAV_Pin GPIO_PIN_11
#define GPIO6_NAV_GPIO_Port GPIOC
#define GPIO5_NAV_Pin GPIO_PIN_12
#define GPIO5_NAV_GPIO_Port GPIOC
#define GPIO4_NAV_Pin GPIO_PIN_2
#define GPIO4_NAV_GPIO_Port GPIOD
#define GPIO3_NAV_Pin GPIO_PIN_3
#define GPIO3_NAV_GPIO_Port GPIOB
#define GPIO2_NAV_Pin GPIO_PIN_4
#define GPIO2_NAV_GPIO_Port GPIOB
#define GPIO1_NAV_Pin GPIO_PIN_5
#define GPIO1_NAV_GPIO_Port GPIOB
#define USART1_TX_NAV_Pin GPIO_PIN_6
#define USART1_TX_NAV_GPIO_Port GPIOB
#define I2C1_SDA_NAV_Pin GPIO_PIN_7
#define I2C1_SDA_NAV_GPIO_Port GPIOB
#define I2C1_SCL_NAV_Pin GPIO_PIN_8
#define I2C1_SCL_NAV_GPIO_Port GPIOB

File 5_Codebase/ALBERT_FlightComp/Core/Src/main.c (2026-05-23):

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
/* Includes ------------------------------------------------------------------*/
#include "main.h"
#include "usb_device.h"

/* USER CODE BEGIN Includes */

#include "usbd_cdc_if.h"
#include <math.h>

#include "LSM6DSLTR.h"
#include "BMM150.h"
#include "BMP390.h"
#include "BMI088.h"

#include "Kalman.h"
#include "RocketModel.h"


/* USER CODE END Includes */

/* USER CODE BEGIN PTD */

/* ============================================================
 *  Inter-chip protocol — NAV ↔ MPU
 *  This struct MUST be byte-identical on both boards.
 *  Layout (32 bytes, little-endian floats):
 *    [0]  sync1 = 0xA1     [16..19] phi   (rad)
 *    [1]  sync2 = 0xB5     [20..23] theta (rad)
 *    [2]  type  = 0x01     [24..27] psi   (rad)
 *    [3]  seq   (rolling)  [28..31] p     (rad/s, bias-corrected)
 *    [4]  flags            ──── waits, that doesn't fit 32 bytes.
 *  Real layout below:
 * ============================================================ */
typedef struct __attribute__((packed)) {
    uint8_t  sync1;        /*  0   LINK_SYNC1          */
    uint8_t  sync2;        /*  1   LINK_SYNC2          */
    uint8_t  type;         /*  2   LINK_TYPE_STATE     */
    uint8_t  seq;          /*  3   rolling counter     */
    uint8_t  flags;        /*  4   bit0 = att_init, bit1 = mag_ref */
    uint8_t  reserved;     /*  5   keep total at 32    */
    float    phi;          /*  6   rad                 */
    float    theta;        /* 10   rad                 */
    float    psi;          /* 14   rad                 */
    float    p;            /* 18   rad/s (bias-corrected) */
    float    q;            /* 22                       */
    float    r;            /* 26                       */
    uint16_t crc;          /* 30   CRC-16/CCITT-FALSE over bytes [0..29] */
} link_state_t;
/* Compile-time size check (C89-portable; fails to compile with a
 * "negative size array" error if the struct is ever the wrong size). */
typedef char link_state_size_check[sizeof(link_state_t) == 32 ? 1 : -1];

/* USER CODE END PTD */

/* USER CODE BEGIN PD */
#define USB_BUFLEN        128

#define LINK_PACKET_LEN   32        /* must equal sizeof(link_state_t)        */
#define LINK_SYNC1        0xA1
#define LINK_SYNC2        0xB5
#define LINK_TYPE_STATE   0x01

#define LINK_FLAG_ATT_INIT   (1u << 0)
#define LINK_FLAG_MAG_REF    (1u << 1)
/* USER CODE END PD */

I2C_HandleTypeDef hi2c1;
I2C_HandleTypeDef hi2c2;

RTC_HandleTypeDef hrtc;

SPI_HandleTypeDef hspi1;
SPI_HandleTypeDef hspi2;

UART_HandleTypeDef huart1;
UART_HandleTypeDef huart2;

/* USER CODE BEGIN PV */

/* =====================================================================
 *  Inter-chip UART link (NAV side)
 * =====================================================================
 *  Handshake:
 *    MPU --INT1_MPU(out)--> INT1_NAV(EXTI rising) :  "I'm sending"
 *    NAV --INT2_NAV(out)--> INT2_MPU(EXTI rising) :  "I'm sending"
 *
 *  On EXTI rising on INT1_NAV the NAV arms HAL_UART_Receive_IT for one
 *  fixed-size packet; HAL_UART_RxCpltCallback raises mpu_rx_ready for
 *  the main loop to consume.
 *
 *  TX direction (NAV -> MPU) carries the rocket state packet at 100 Hz
 *  via nav_send_state().
 * ===================================================================== */

uint8_t  link_rx_buf[LINK_PACKET_LEN];
uint8_t  link_tx_buf[LINK_PACKET_LEN];
volatile uint8_t mpu_rx_ready = 0;       /* set by HAL_UART_RxCpltCallback */
volatile uint8_t link_tx_busy = 0;       /* gates nav_send_packet re-entry */


BMI088 imu1;
LSM6DSLTR imu2;
BMM150 magneto;
BMP390 prs;

Kalman      ekf;            //  6-DOF strapdown EKF (primary state estimator)
RocketModel rmdl;           //  9-DOF dynamic model, runs in parallel for validation

/* Process noise (diagonal).  u,v,w [m/s per sqrt(s)]^2  ;  phi,theta,psi [rad/s per sqrt(s)]^2 */
float Q_ekf[6] = {
    1.0e-2f, 1.0e-2f, 1.0e-2f,   /* velocity: smaller Q fights drift when obs are sparse */
    1.0e-3f, 1.0e-3f, 1.0e-3f
};

/* Measurement noise (tune against static bench data) */
float R_accel[3] = { 0.5f, 0.5f, 0.5f };   /* (m/s^2)^2   */
float R_mag      = 0.1f;                    /* rad^2       */
float R_baro     = 1.0f;                    /* (m/s)^2     */
float R_gps[3]   = { 0.25f, 0.25f, 0.25f }; /* (m/s)^2     */
float R_zupt     = 0.01f;                   /* tight: believe v = 0 when static */

/* Placeholders — hook up real servo commands and a thrust-time curve later */
float cmd_delta_eta  = 0.0f;
float cmd_delta_zeta = 0.0f;
float cmd_delta_r    = 0.0f;
float cmd_thrust_N   = 0.0f;

/* Sensor bias estimates — updated in-place during static detection on the pad.
 * gyr_bias absorbs the ~0.1-0.5 deg/s BMI088 offset that otherwise walks phi.
 * acc_bias absorbs accel DC offset so Kalman_UpdateAccel sees a true +g vector. */
float gyr_bias[3] = {0.0f, 0.0f, 0.0f};
float acc_bias[3] = {0.0f, 0.0f, 0.0f};

/* Nav-frame magnetic reference, captured once on pad during static hold.
 * Fixes the "phi=0" heading to whatever orientation the rocket sits in at t0. */
float            mag_nav[3]                = {0.0f, 0.0f, 0.0f};
uint8_t          mag_reference_captured    = 0;
volatile uint8_t static_now                = 0;   /* set by gyro handler each tick */

/* Tilt-compensated phi from magnetometer.
 *   body mag  =  R_x(phi) R_y(theta) R_z(psi) * mag_nav
 * With A = -sy*mnx + cy*mny,  B = st*cy*mnx + st*sy*mny + ct*mnz :
 *   m_by = A*cp + B*sp,   m_bz = B*cp - A*sp
 * → phi = atan2(m_by*B - m_bz*A,  m_by*A + m_bz*B)
 * Returns 0 when the horizontal-field basis degenerates (|A|,|B| both small). */
static inline int phi_from_mag(const float m_b[3], const float mn[3],
                               float theta, float psi, float *phi_out)
{
    const float st = sinf(theta), ct = cosf(theta);
    const float sy = sinf(psi),   cy = cosf(psi);
    const float A = -sy*mn[0] + cy*mn[1];
    const float B =  st*cy*mn[0] + st*sy*mn[1] + ct*mn[2];
    if (A*A + B*B < 1e-6f) return 0;
    *phi_out = atan2f(m_b[1]*B - m_b[2]*A,
                      m_b[1]*A + m_b[2]*B);
    return 1;
}


/* Interrupt Flags and timers*/
volatile uint8_t imu1_acc_drdy = 0;
volatile uint8_t imu1_gyr_drdy = 0;
volatile uint8_t bmp390_drdy   = 0;

volatile uint32_t acc_t = 0,    gyr_t = 0,    bmp_t = 0,	last_gyr_t = 0;

uint8_t vehiclestate = 0;
// Test counters
//volatile uint32_t imu1_acc_irq_cnt = 0;
//volatile uint32_t imu1_gyr_irq_cnt = 0;
//volatile uint32_t bmp390_irq_cnt   = 0;



/* USB data buffer */
uint8_t usbTxBuf[USB_BUFLEN];
uint16_t usbTxBufLen;
/* USER CODE END PV */

void SystemClock_Config(void);
static void MX_GPIO_Init(void);
static void MX_SPI1_Init(void);
static void MX_SPI2_Init(void);
static void MX_I2C1_Init(void);
static void MX_I2C2_Init(void);
static void MX_USART1_UART_Init(void);
static void MX_USART2_UART_Init(void);
static void MX_RTC_Init(void);
/* USER CODE BEGIN PFP */

void HAL_GPIO_EXTI_Callback(uint16_t GPIO_Pin);
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

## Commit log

2025-09-29 Add initial files for flight computer and dashboard setup
    [ALBERT_FLIGHTCOMPUTER.kicad_pcb, ALBERT_FLIGHTCOMPUTER.kicad_sch]
2025-09-30 Refactor code structure for improved readability and maintainability
    [ALBERT_FLIGHTCOMPUTER.kicad_sch]
2025-11-02 Add files via upload
    hirohito ist der goat
    [Assembly.cfg, Heck_Test.cfg]
2025-11-27 Add lock file for ALBERT_FLIGHTCOMPUTER PCB design
    [ALBERT_FLIGHTCOMPUTER.kicad_pcb, ALBERT_FLIGHTCOMPUTER.kicad_sch, ALBERT_FLIGHTCOMPUTER.step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]
2025-12-01 update pcb
    [ALBERT_FLIGHTCOMPUTER.kicad_pcb, GPS & LORA.kicad_sch, NAVComputer_sch.kicad_sch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]
2025-12-02 Changed motor class from F to H because boring Wirtschaft i don't give a fuck
2025-12-09 Add production files and update project lock file
    - Added new production IT1 zip file for ALBERT_FLIGHTCOMPUTER.
    - Removed obsolete test zip file from production directory.
    - Created a lock file for the KiCad schematic with user and hostname information.
    [ALBERT_FLIGHTCOMPUTER.kicad_pcb, ALBERT_FLIGHTCOMPUTER.kicad_sch, GPS & LORA.kicad_sch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]
2025-12-11 hallo der papa is da
    [ALBERT_FLIGHTCOMPUTER.kicad_pcb, ALBERT_FLIGHTCOMPUTER.kicad_sch, Connectivity.kicad_sch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]
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2025-12-31 der silvester hase kommt vor dem sturm in einer socke
    [ALBERT_FLIGHTCOMPUTER.kicad_pcb]
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2026-01-07 Pregnant Women, DON’T USE TYLENOL UNLESS ABSOLUTELY NECESSARY, DON’T GIVE TYLENOL TO YOUR YOUNG CHILD FOR VIRTUALLY ANY REASON, BREAK UP THE MMR SHOT INTO THREE TOTALLY SEPARATE SHOTS (NOT MIXED!), T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
    [ALBERT_FLIGHTCOMPUTER.kicad_pcb, ALBERT_FLIGHTCOMPUTER.kicad_sch, ALBERT_FLIGHTCOMPUTER.step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]
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2026-01-16 ich sexualisiere persönlichkeitsstörung nicht weil ich mich darüber lustig mache sondern weil ichs geil finde also wenn du borderline hast und amphetaminsüchtig bist bitte piss mir ins maul
    [Assembly.cfg, Assembly_FlightComputer.cfg, Assembly_Gesamt.cfg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]
2026-01-17 ich simuliere meinen orgasmus
    [NACA0012_SIM.stl, NACA0012_SIM_downscaled.stl]
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2026-01-21 reicht für heute openfoam wird mich noch ins grab bringen
    [NACA0012.stl]
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2026-02-22 5d druck
    [Abstandhalter_Finne_Servo.3mf, Abstandhalter_Servo_Komadori_BLYAAAAT.3mf, Drehmomentaufnahme_Finne_Fixed.3mf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]
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2026-02-24 netherite ingots
    [ALBERT_assembly.cfg, ALBERT_assembly.obj, finne_windkanal.3mf]
2026-02-25 Nordkoreas Machthaber Kim Jong Un ist bei dem alle fünf Jahre stattfindenden Parteitag seiner Arbeiterpartei als Generalsekretär wiedergewählt worden. Die Entscheidung sei am Sonntag "entsprechend de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
    [Kleine_Teile.3mf]
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2026-02-26 hingekackt und hingeschissen
    [ALBERT_assembly.cfg, Asm2.cfg]
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2026-02-28 so das jz drucken
    [Servomotor_Halterung.3mf]
2026-03-01 timmähh
    [ALBERT_assembly.cfg, albert_5_aoa_fins.3mf, albert_5_aoa_fins.stp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]
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2026-03-02 Dale a tu cuerpo alegría, Macarena Que tu cuerpo es pa' darle alegría y cosa buena Dale a tu cuerpo alegría, Macarena Hey Macarena, ay! Dale a tu cuerpo alegría, Macarena Que tu cuerpo es pa' darle a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
    [Servomotor_Halterung.3mf]
2026-03-02 #🇯🇵japan is turning footsteps into electricity!
    Using piezoelectric tiles, every step you take generates a small amount of energy. Millions of steps together can power LED lights and displays in busy places like Shibuya Station. A brilliant way to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
    [ALBERT_assembly.cfg, Abdeckung_Arsch.3mf, Drehmomentaufnahme_Finne.3mf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]
2026-03-03 holy fuck stewie im shitting
    [ALBERT_assembly.cfg, Servomotor_Halterung.3mf]
2026-03-03 8 hours later, we fired 47 cruise missiles on the iraqi intelligence center. this was at night and we killed the janitor
    [NACA0012.3mf]
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2026-03-07 Quid pro quo; bitch ich kriege einen ständer; bald steht der benz da; sunshine sunshine reggae; bakerman bada bada bada dada is baking bread; subaweya alaboya combagaweja
    [Power.kicad_sch]
2026-03-08 Neu-unbenützt--4 Teile -Umschnall-Set--1 Slip ouvert--1 Natur -Dildo--1 G-Punkt-Dildo---1 Anal-Dildo--privat Verkauf keine Gewährleistung und Rückgaberecht .
    [ALBERT_FLIGHTCOMPUTER.kicad_pcb]
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2026-03-19 Folgendes Problem ist Matrix gleich Matrix oder Pizza mal Teflon gleich Scorpion Scorpion dreimal Skorpion ja kennst du Unterschied zwischen Scorpion auf Englisch und Scorpion auf Deutsch
2026-03-19 Crack ist eine extrem süchtig machende, rauchbare Form von Kokain, die aus Kokainhydrochlorid unter Zugabe von Backpulver oder Ammoniak hergestellt wird. Es wirkt sehr schnell (innerhalb von Sekunden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
2026-03-20 big yahu/big stein
    [ALBERT_assembly.cfg]
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2026-03-23 alcohol, cigarettes and dry humping
    [ALBERT_assembly.cfg, Abdeckung_Motor_Heck.3mf, schablone_bohrungen_oben.3mf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]
2026-03-23 Die EU ruft die Renaissance der Atomkraft aus – und Österreich schreit: "Schleich di!"
    [ALBERT_FLIGHTCOMPUTER.kicad_sch, GPS & LORA.kicad_sch, MPU_Peripherals.kicad_sch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]
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2026-03-24 Teststoff für Test am 08.04.2026 Unternehmensgründung Seite 249-255, Seite 261-283 Finanzierung Seite 286-325
    Ach! und Weh!,
    Mord! Zetter! Jammer / Angst / Kreuz! Marter! Würme! Plagen.
    Pech! Folter! Hencker! Flamm! Stank! Geister! Kälte! Zagen!
    Ach vergeh!
    Tiff’ und Höh’!
    Meer! Hügel! Berge! Fels wer kann die Pein ertragen?
    Schluck Abgrund! Ach schluck’ ein! die nichts denn ewig klagen.
    Je und Eh!
    Schreckliche Geister der dunkelen Hölen / ihr die ihr martret und Marter erduldet
    Kann denn der ewigen Ewigkeit Feuer / nimmermehr büßen dies was ihr verschuldet?
    O grausamm’ Angst stets sterben / sonder sterben!
    Dies ist Flamme der grimmigen Rache / die der erhitzete Zorn ange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
2026-03-25 Der Papa ist King, doch das heißt nicht, dass du ein Prinz bist Deine Mom ist meine Schwester, richtig, das ist Inzest Ich schüttel' meinen Sohnemann, Kurzer, mach die Augen auf Ich kann dich nicht z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
    [schablone_bohrungen_oben.3mf]
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2026-03-26 na aber hallo csv
    [daten_klein.csv, daten_klein2.csv, daten_klein3.csv]
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2026-03-26 entweder ich hänge mich auf oder ich hänge mich auf
    [Finnen_Halterung.3mf, Servomotor_Halterung.3mf]
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2026-04-20 aint that a bitchhhhhhhhhHhhh
    [ALBERT_assembly.cfg, Kolben.3mf]
2026-04-20 ai slop
    [ALBERT_assembly.cfg, Drehmomentaufnahme_Finne_Fixed.3mf, Drehmomentaufnahme_Servo_Fixed.3mf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]
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2026-05-15 heute geht ne session ich bin meist im studio nackt
    [ALBERT_assembly.cfg, Asm_test.cfg, FlightComputer_platform.3mf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]

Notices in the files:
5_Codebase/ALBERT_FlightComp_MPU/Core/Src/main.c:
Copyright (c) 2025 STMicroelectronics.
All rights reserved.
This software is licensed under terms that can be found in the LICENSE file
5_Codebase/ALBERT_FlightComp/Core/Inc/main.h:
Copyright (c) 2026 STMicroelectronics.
